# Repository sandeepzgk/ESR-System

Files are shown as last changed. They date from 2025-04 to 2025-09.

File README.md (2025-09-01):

## Electrical Stochastic Resonance (ESR) System : Source Code

This repository hosts the full source for an end‑to‑end ESR system:
- A web‑based RC circuit analyzer (Simulator)
- MicroPython firmware for a Pico W/2W audio device (Firmware)
- A KiCad hardware design for the device (PCB)
- A local experiment runner for ABX/QUEST studies (ABXTester)

Hosted analyzer (no install): https://sandeepzgk.github.io/ESR-System/

### Quick links
- Simulator (web analyzer): Simulator/README.md : hosted at https://sandeepzgk.github.io/ESR-System/
- Firmware (Pico W/2W): Firmware/README.md
- PCB (sr‑device KiCad): PCB/README.md
- ABXTester (experiment runner): ABXTester/readme.md

### Repository structure
- Simulator/ : React + TypeScript single‑page app for ESR RC analysis (sine and noise modes), Tailwind UI, GitHub Pages deploy
- Firmware/ : MicroPython code for Wi‑Fi control and I2S audio playback (HTTP endpoints: play/gain/led/status), Q15 volume scaling
- PCB/ : KiCad project (schematic/PCB), repo‑local libraries and production outputs (v1, v2); JLC importer utility
- ABXTester/ : Flask‑based local runner for experiments (QUEST thresholding + ABX trials), CSV/JSON results

### Citations

#### APA
Kollannur, S., Zhao, F., Chen, Y., & Culbertson, H. (2025). Electrical Stochastic Resonance (ESR) System [Computer software]. GitHub. https://github.com/sandeepzgk/ESR-System

#### MLA
Kollannur, S., Zhao, F., Chen, Y., and Culbertson, H. Electrical Stochastic Resonance (ESR) System. 2025. GitHub, https://github.com/sandeepzgk/ESR-System.

#### Chicago
Kollannur, S., F. Zhao, Y. Chen, and H. Culbertson. 2025. Electrical Stochastic Resonance (ESR) System. GitHub repository. https://github.com/sandeepzgk/ESR-System.

#### BibTeX
```bibtex
@software{esr_system_2025,
  author    = {Kollannur, S. and Zhao, F. and Chen, Y. and Culbertson, H.},
  title     = {Electrical Stochastic Resonance (ESR) System},
  year      = {2025},
  publisher = {GitHub},
  url       = {https://github.com/sandeepzgk/ESR-System},
  note      = {A system for electrical stochastic resonance research including circuit analysis, firmware, hardware design, and experiment tools}
}
```

#### Software Citation Format
Kollannur, S., Zhao, F., Chen, Y., & Culbertson, H. (2025). Electrical Stochastic Resonance (ESR) System [Source code]. GitHub. https://github.com/sandeepzgk/ESR-System : A system for electrical stochastic resonance research including circuit analysis, firmware, hardware design, and experiment tools.

### Brief technical summary
- Web analyzer: React 18 + TypeScript, Tailwind; static SPA deployable to GitHub Pages
- Firmware: MicroPython on RP2040 (Pico W/2W), machine.I2S TX, HTTP API over Wi‑Fi
- Hardware: KiCad project with pinned repo‑local symbol/footprint/3D libraries; production files for fabrication
- Experiments: Python (Flask) with two‑channel audio playback, CSV/JSON logging, QUEST thresholding

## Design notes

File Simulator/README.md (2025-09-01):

## Simulator : ESR RC Circuit Analysis (React + TypeScript)

### 1) Overview
A Create‑React‑App project to explore an AC parallel RC circuit under sine and white‑noise excitation, with safety guidance and units. Features:
- Interactive parameter controls with unit conversion (V, Ω, F, Hz)
- Modes: sine wave and white noise (band‑limited)
- Current distribution and frequency response visualizations
- Noise regime classification via effective ωRC across a band

Key files
- src/RCCircuitAnalysis.tsx : main UI composition
- src/circuitCalculations.ts : unified math for sine and noise modes (ω, effective ωRC, regime)
- src/hooks/useRCCircuit.ts : state, validation, defaults
- src/components/* : charts, controls, results, errors, theory modal
- public/index.html : CRA shell; title set to "ESR Simulator"

### Hosted version
- Use the web app without local setup: https://sandeepzgk.github.io/ESR-System/
- The site is built from this Simulator folder via GitHub Pages (see package.json scripts)

### 2) How to run / deploy
Local dev
- Node 18 recommended
- npm install
- npm start (serves at http://localhost:3000)

Build
- npm run build (outputs to build/)

GitHub Pages
- package.json includes homepage, predeploy, deploy using gh-pages
- npm run deploy publishes build/ to GitHub Pages

Tailwind CSS
- Configured via tailwind.config.js and postcss.config.js; styles in src/index.css

### 3) Where it has been tested
- Local development on Node 18 (per workflow/notes)
- Desktop and mobile layouts; responsive tweaks for small screens

### 4) History and rationale (commit highlights)
- fbdffec (Simulator): Initial CRA app with modular RC analysis and Tailwind styling
- 0ad58a2 (Tailwind): Local Tailwind setup; build pipeline integrated
- 8b760ef/139e43c: 16:9 layout and dashboard‑friendly grid with bug fixes
- b4ca46e: Units system introduced; validation against physical limits
- 65beb42: Added white‑noise mode and UI for band limits
- b949c22 → 863e207 → 1286340: Noise math refined; centralized in circuitCalculations.ts; dimensional correctness
- d57948b/f4cb959: GitHub Pages workflow hardened; caching removed to fix builds
- a7b0789: Homepage switched to ESR‑System for correct Pages base URL

Design choices
- Single math module to avoid duplicated logic between modes
- Declarative UI with validation and explicit unit factors
- CRA + Tailwind for fast iteration; gh‑pages for simple hosting

### 5) Brief technical summary
- Stack: React 18, TypeScript 4.9, CRA 5, Tailwind 3, gh-pages
- Testing: react-scripts test + Testing Library stubs present
- Build targets modern browsers (per browserslist)
- No server required for runtime; static SPA deployable to Pages or any static host

The tissue is modeled as a parallel RC circuit (simplified electrical model)

References used in documentation and model validation:
- Alexander & Sadiku "Fundamentals of Electric Circuits" Chapter 9: Sinusoidal steady-state analysis
- Hayt & Kemmerly "Engineering Circuit Analysis" Chapter 10: AC circuit theory
- IEC 60479 series: Electrical Safety Thresholds and frequency dependence
- IEC 60601-1:2012: Medical device leakage current limits
- MIT OpenCourseWare 8.02T: AC circuit coverage with experimental validation
- Electronics Tutorials: Impedance and phasor analysis with worked examples

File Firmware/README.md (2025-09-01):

## Firmware : Pico 2W Audio Playback and Control

### 1) Overview
Firmware for a Raspberry Pi Pico W/2W running MicroPython to:
- Serve a simple HTTP API over Wi‑Fi for play/gain/LED/status
- Stream stereo PCM audio over I2S to a DAC and class‑D amplifier
- Read raw PCM from on‑device storage with triple‑buffering

Key modules
- main.py : boots Wi‑Fi and hardware, polls for requests, and drives playback
- network_controller.py : Wi‑Fi connect with exponential backoff; simple HTTP server; thread‑safe request passing
- hardware_controller.py : I2S init, DAC/amp control, LED control; in‑place Q15 volume scaling via a @micropython.viper function
- wav_file_player.py : RawFilePlayer: triple‑buffered raw PCM reader with wrap‑around
- config.json : pins, audio parameters (sample_rate, bits, buffer sizes), Wi‑Fi creds
- boot.py : ensures the amplifier shutdown pin is safe on boot
- misc/ : api-tester.py (exercise endpoints), wave-converter.py (WAV→RAW tool)

HTTP endpoints
- GET /play?duration=SECONDS&volume=0.0..1.0 : queue a fixed‑duration playback
- GET /gain?level=0..3 : set amplifier gain pins
- GET /led?num=0..4&state=on|off : control LEDs (0 = all)
- GET /status : return Wi‑Fi/server state and IP

Audio path
- I2S configured from config["audio"] (rate, bits, DMA/buffer sizes)
- Raw PCM file read in fixed‑size frames, scaled in‑place to Q15, written to I2S

### 2) How to deploy / run on hardware
Prerequisites
- Raspberry Pi Pico W/2W flashed with MicroPython
- A RAW PCM file on the device (default filename: my_sound.raw)
- Correct wiring for I2S BCK/LRCK/DATA to the DAC and amp control pins per config.json

Steps
1) Configure
- Edit Firmware/config.json: set network.ssid/password; verify pins and audio settings
- Optionally change audio.playback_frames/dma_buffer_frames for your I2S driver
2) Copy files to the board
- Copy all Firmware/*.py and config.json to the device (e.g., Thonny, mpremote)
- Copy your RAW audio file as my_sound.raw (or update main.py accordingly)
3) Boot and run
- Reset the board; boot.py sets amp shutdown low; main() starts automatically if invoked
- The Wi‑Fi controller runs on the second core/thread and starts the HTTP server
4) Invoke playback (examples)
- curl "http://<PICO_IP>/play?duration=5&volume=0.5"
- curl "http://<PICO_IP>/gain?level=2"
- curl "http://<PICO_IP>/led?num=0&state=on"; curl "http://<PICO_IP>/status"

Converting WAV to RAW
- Use Firmware/misc/wave-converter.py to resample/convert WAV → interleaved RAW matching config["audio"]

### 3) Where it has been tested
- On Raspberry Pi Pico 2W hardware with MicroPython (RP2040 + Wi‑Fi)
- Exercised via misc/api-tester.py and curl from a local network
- Exact MicroPython version and DAC/amp models depend on your setup; pins are configurable

### 4) History and rationale (commit highlights)
- 3d118a1 (Firmware): Initial firmware: I2S + Wi‑Fi + raw file player; simple HTTP API to decouple host and device
- c961120 (misc tools): Added wave-converter.py and moved api-tester under misc for easier audio prep and endpoint testing

Design choices
- Fixed‑point Q15 scaling in a @micropython.viper routine for fast per‑buffer volume without floating point
- Exponential backoff Wi‑Fi connect with LED signaling for robustness
- Triple‑buffer file reader to minimize glitches while looping
- Config‑driven pins/buffers so firmware can be tuned without code changes

### 5) Brief technical summary
- Platform: MicroPython on RP2040 (Pico W/2W) with _thread concurrency
- Peripherals: machine.I2S TX; GPIOs for DAC mute, amp gain (2 bits), amp shutdown, LEDs
- Networking: network + sockets, simple GET API, cooperative loop with short timeouts
- Audio: raw interleaved PCM, DMA‑sized I2S buffer, optional playback_frames override
- Synchronization: lock‑protected request queue (play/gain), state flags to reject concurrent play

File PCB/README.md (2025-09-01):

## PCB SR Device KiCad Project

### 1) Overview
KiCad project for the ESR hardware: a Pico‑based audio playback/amp board ("sr-device"). Includes:
- KiCad schematic, PCB, and project files (sr-device.kicad_*)
- Curated symbol/footprint/3D libraries under PCB/lib for key parts (DAC, amplifier, regulators, passives, connectors)
- Production outputs under PCB/production/v1 and v2 (BOM, positions, designators, zipped fab packages)
- jlcimporter.py utility to generate and normalize part libraries using JLC2KiCadLib

Notable parts
- DAC: PCM5100A
- Amplifier: TPA3112D1
- Regulators: LM78M05C, LM7812S, LM1085IS-12, AP7333-33
- Inductors/caps/resistors; Pico headers/footprints; custom logos

### 2) How to open / produce outputs
Open in KiCad 7/8
- Open PCB/sr-device.kicad_pro; KiCad will resolve sym-lib-table and fp-lib-table to PCB/lib/*

Generate fabrication
- Use KiCad’s Plot and Fabrication Toolkit (options in fabrication-toolkit-options.json)
- Export Gerbers, drill files, position files, and BOM as needed

JLC integration workflow
- jlcimporter.py wraps JLC2KiCadLib to create per‑part libraries under PCB/lib/<MFR_PART>/
- It normalizes filenames (symbol.kicad_sym, footprint.kicad_mod, model.step) and updates lib tables
- Run from PCB/: python jlcimporter.py --lcsc_part_numbers C12345 C67890

### 3) Where it has been tested
- Designed and opened in KiCad; produced v1 and v2 outputs in PCB/production
- Libraries resolved via sym-lib-table and fp-lib-table within this project (KIPRJMOD relative paths)

### 4) History and rationale (commit highlights)
- 79621ca (PCB): Initial KiCad project checked in with curated libraries and production artifacts (v1, v2)
- Custom library structure chosen for reproducibility and to avoid external dependency drift; jlcimporter.py automates bringing JLC parts into repo‑local libs

Design choices
- Repo‑local symbol/footprint/3D models for repeatable builds and offline use
- KIPRJMOD‑relative paths in lib tables so the project remains portable
- Versioned production output directories to track released fab packages

### 5) Brief technical summary
- EDA: KiCad project with sym/fp tables pinned to PCB/lib
- Manufacturing: BOM/pos/designator exports for JLC; STEP models included for 3D
- Utilities: Python importer normalizes JLC outputs and patches lib tables

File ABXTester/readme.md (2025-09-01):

## ABXTester : Experiment Runner

### 1) Overview
ABXTester is a local Flask web app for running audio psychophysics experiments that combine:
- QUEST threshold estimation to calibrate the stochastic-resonance (SR) noise level
- ABX trials over a texture dataset
- Durable CSV/JSON logging

Core modules
- managers/flaskapp.py : Minimal page queue and event routing to Jinja2 templates
- managers/stereoaudioplayer.py : Two‑channel playback (soundfile + simpleaudio) with independent gains
- managers/questestimation.py : QUEST wrapper (max trials, start value)
- managers/experimentreader.py : CSV‑driven condition sequencing
- managers/atomicwriter.py : Atomic appends for results files

Data layout (relative to ABXTester/)

``` Note: This data is not included because of IP. Please contact the author for more information. ```
- dataset/v2024dataset.csv : Trial/experiment conditions
- media/textures/ : Left‑channel textures (WAV)
- dataset/stochastic_noise.wav : Right‑channel SR noise (WAV)
- results/ : Output CSV and QUEST JSON snapshots

Entry point: main.py orchestrates page flow (instructions → QUEST → trial → experiment → survey) and wires event handlers.

### 2) How to deploy/run
Prerequisites
- Conda/Miniconda
- Working audio output device
- Windows is the primary target (env includes pywin32/pypiwin32); Linux/macOS may work with minor tweaks

Steps
1. Environment
   - conda env create -f environment.yml
   - conda activate abx_tester
2. Assets
   - Ensure dataset/v2024dataset.csv, dataset/stochastic_noise.wav, and media/textures/* exist
   - Create results/ directory if missing
3. Launch
   - python main.py <PARTICIPANT_ID>
   - Open http://127.0.0.1:5000
4. Operation
   - Use the web UI; app posts to /event and advances pages via a queue
   - Outputs: results/<PARTICIPANT_ID>_experiment_results.csv and <PARTICIPANT_ID>_quest_results.csv (+ .json)

Notes
- Sample rates must match between the two input WAVs; the player enforces this
- Right channel SR amplitude is QUEST_MEAN × SRPresentationLVL (per trial row)

### 3) Where it has been tested
- Windows 10/11 with Anaconda/Miniconda
- Python 3.11 as pinned in environment.yml
- Chromium‑based browsers locally
- simpleaudio backend (WASAPI/DirectSound on Windows)

### 4) History and rationale (commit highlights)
- d90c32e (ABXTester): Initial Flask app with audio playback, CSV I/O, QUEST, and templates : goal: unify thresholding and ABX in a lightweight local runner with durable logging
- Environment pinned in environment.yml for reproducible audio/science stacks (NumPy/SciPy/Librosa/simpleaudio/PsychoPy)

Design choices
- Minimal Flask wrapper (page queue + event routing) for easy experiment customization
- Atomic writes to prevent truncated CSVs in the presence of interruptions
- Explicit media/dataset layout to separate stimuli from code

### 5) Brief technical summary
- Language: Python 3.11
- Frameworks/Libraries: Flask + Jinja2, NumPy, soundfile (libsndfile), simpleaudio, pandas, pytz
- Architecture: Single‑process Flask; event‑driven page transitions; synchronous audio playback guarded by a simple AudioManager
- I/O: CSV conditions → in‑memory row; responses → atomic CSV + QUEST JSON snapshots

# Conda Environment Setup for ABX Tester Project

This guide will help you set up a Conda environment for the ABX Tester project using the `environment.yml` file.

## Prerequisites

- [Anaconda](https://www.anaconda.com/products/individual) or [Miniconda](https://docs.conda.io/en/latest/miniconda.html) installed on your system.

## Setup Steps

### 1. Clone the Project Repository (if applicable)

If your project is in a Git repository, clone it using the command below. Otherwise, navigate to your project directory.

```bash
git clone <repository-url>
cd <project-directory>
```

### 2. Create the Conda Environment

Create the Conda environment from the provided `environment.yml` file:

```bash
conda env create -f environment.yml
```

This will:
- Create a new Conda environment named `abx_tester`.
- Install all the necessary dependencies listed in the `environment.yml` file using Conda and pip.

### 3. Activate the Environment

After the environment is created, activate it with the following command:

```bash
conda activate abx_tester
```

### 4. Verify the Installation

To verify that everything is installed correctly, you can run a simple Python script that imports all the required libraries:

```python
import numpy
import pandas
import scipy
import matplotlib
import seaborn
import librosa
import soundfile
import sklearn
import pytz
import flask
import psychopy
import simpleaudio

print("All libraries imported successfully!")
```

Save this script as `test_imports.py` and run it:

```bash
python test_imports.py
```

If you see the success message without any errors, your environment is set up correctly.

### 5. Updating the Environment

If new dependencies are added to the project in the future, you can update the environment by running:

```bash
conda env update --file environment.yml --prune
```

This will install any new dependencies and remove packages no longer required.

### 6. Removing the Environment

If you ever need to remove the Conda environment, you can do so with:

```bash
conda remove --name abx_tester --all
```

## Troubleshooting

- **If you encounter issues with PyAudio**, you might need to install `portaudio`:
  ```bash
  conda install -c anaconda portaudio
  ```

- **For issues with PsychoPy**, you can try reinstalling it:
  ```bash
  conda install -c conda-forge psychopy
  ```

- **On Windows**, if you encounter issues with `librosa`, try installing `numpy` with MKL:
  ```bash
  conda install -c conda-forge numpy=1.21
  ```

## Environment Overview

### `environment.yml` Contents:
```yaml
name: abx_tester
channels:
  - defaults
  - conda-forge
dependencies:
  - python=3.8
  - numpy
  - pandas
  - matplotlib
  - seaborn
  - scipy
  - soundfile
  - psychopy
  - librosa
  - flask
  - scikit-learn
  - pip
  - pip:
      - simpleaudio
      - pytz
```

This file lists the Conda and pip packages needed to run the project. Conda will install the core libraries, while pip will handle the few additional Python-only packages.

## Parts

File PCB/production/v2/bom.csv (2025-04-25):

Designator | Footprint | Quantity | Value | LCSC Part #
C1, C4 | 0603 | 2 | 2.2uF | C57895
C10, C12, C22, C7 | 0603 | 4 | 10uF | C386081
C11, C14, C15, C16, C17, C19, C24, C27, C5, C8, C9 | 0603 | 11 | 100nF | C88219
C13, C20, C21, C29, C30, C31, C32, C33, C6 | 0603 | 9 | 1uF | C841050
C18 | 0603 | 1 | 0.22uF | C107083
C2, C3 | 0603 | 2 | 2.2nF | C2835509
C23, C26, C34, C36, C40, C41 | 0603 | 6 | 1nF | C340644
C25, C28 | CP_Elec_6.3x5.4 | 2 | 100uF | C2887272
C35, C37 | 0603 | 2 | 0.68uF | C694504
C38, C39 | 0603 | 2 | 0.47uF | C162281
C43 | TAJC686K016RNJ | 1 | 68uF | C7220
D1, D2, D3, D4, D5 | 0603 | 5 | LED_Small | C89811
FB1, FB3 | 0805 | 2 | 80Ω | C2971887
FB2, FB4 | 1806 | 2 | 75Ω | C14586
J1, J2 | KF301-5_0-2P | 2 | KF301-5_0-2P | C474881
J3 | PinHeader_1x02_P2.54mm_Vertical | 1 | Conn_01x02_Pin | DNP
L1, L2 | IHLP3232DZER220M11 | 2 | 22uH | C845053
R1, R2, R3 | 0603 | 3 | 56R | C227967
R11, R12, R13, R14, R21 | 0603 | 5 | 1K | C73797
R15, R16, R17, R18, R19, R20, R4, R7 | 0603 | 8 | 10K | C465463
R22, R23, R24 | 0603 | 3 | 10R | C441910
R5, R6 | 0603 | 2 | 470R | C114669
RV1 | VG039NSNXTB103 | 1 | 10K, originally C515300, now using, C719176 | C719176
SW1 | PTS636SK25SMTRLFS | 1 | PTS636SK25SMTRLFS | C2689642
SW2 | SS-12D11L7 | 1 | SS-12D11L7 | C2884775
U1 | RPi_Pico_SMD_TH | 1 | Pico | DNP
U2 | TO-263-3_TabPin4 | 1 | LM7812S/TR, was LM1085IS-12/NOPB, originally C130908, now C507140, changed for cost | C507140
U11 | TPA3112D1PWPR | 1 | TPA3112D1PWPR | C133544
U3 | Package_SO:TSSOP-20_4.4x6.5mm_P0.65mm | 1 | PCM5100APWR | C131154
U8 | LM78M05CDTX-NOPB | 1 | LM78M05CDTX/NOPB, originally C544492, now using, C5145267 | C5145267
U9 | AP7333-33SRG-7 | 1 | AP7333-33SRG-7 | C150745

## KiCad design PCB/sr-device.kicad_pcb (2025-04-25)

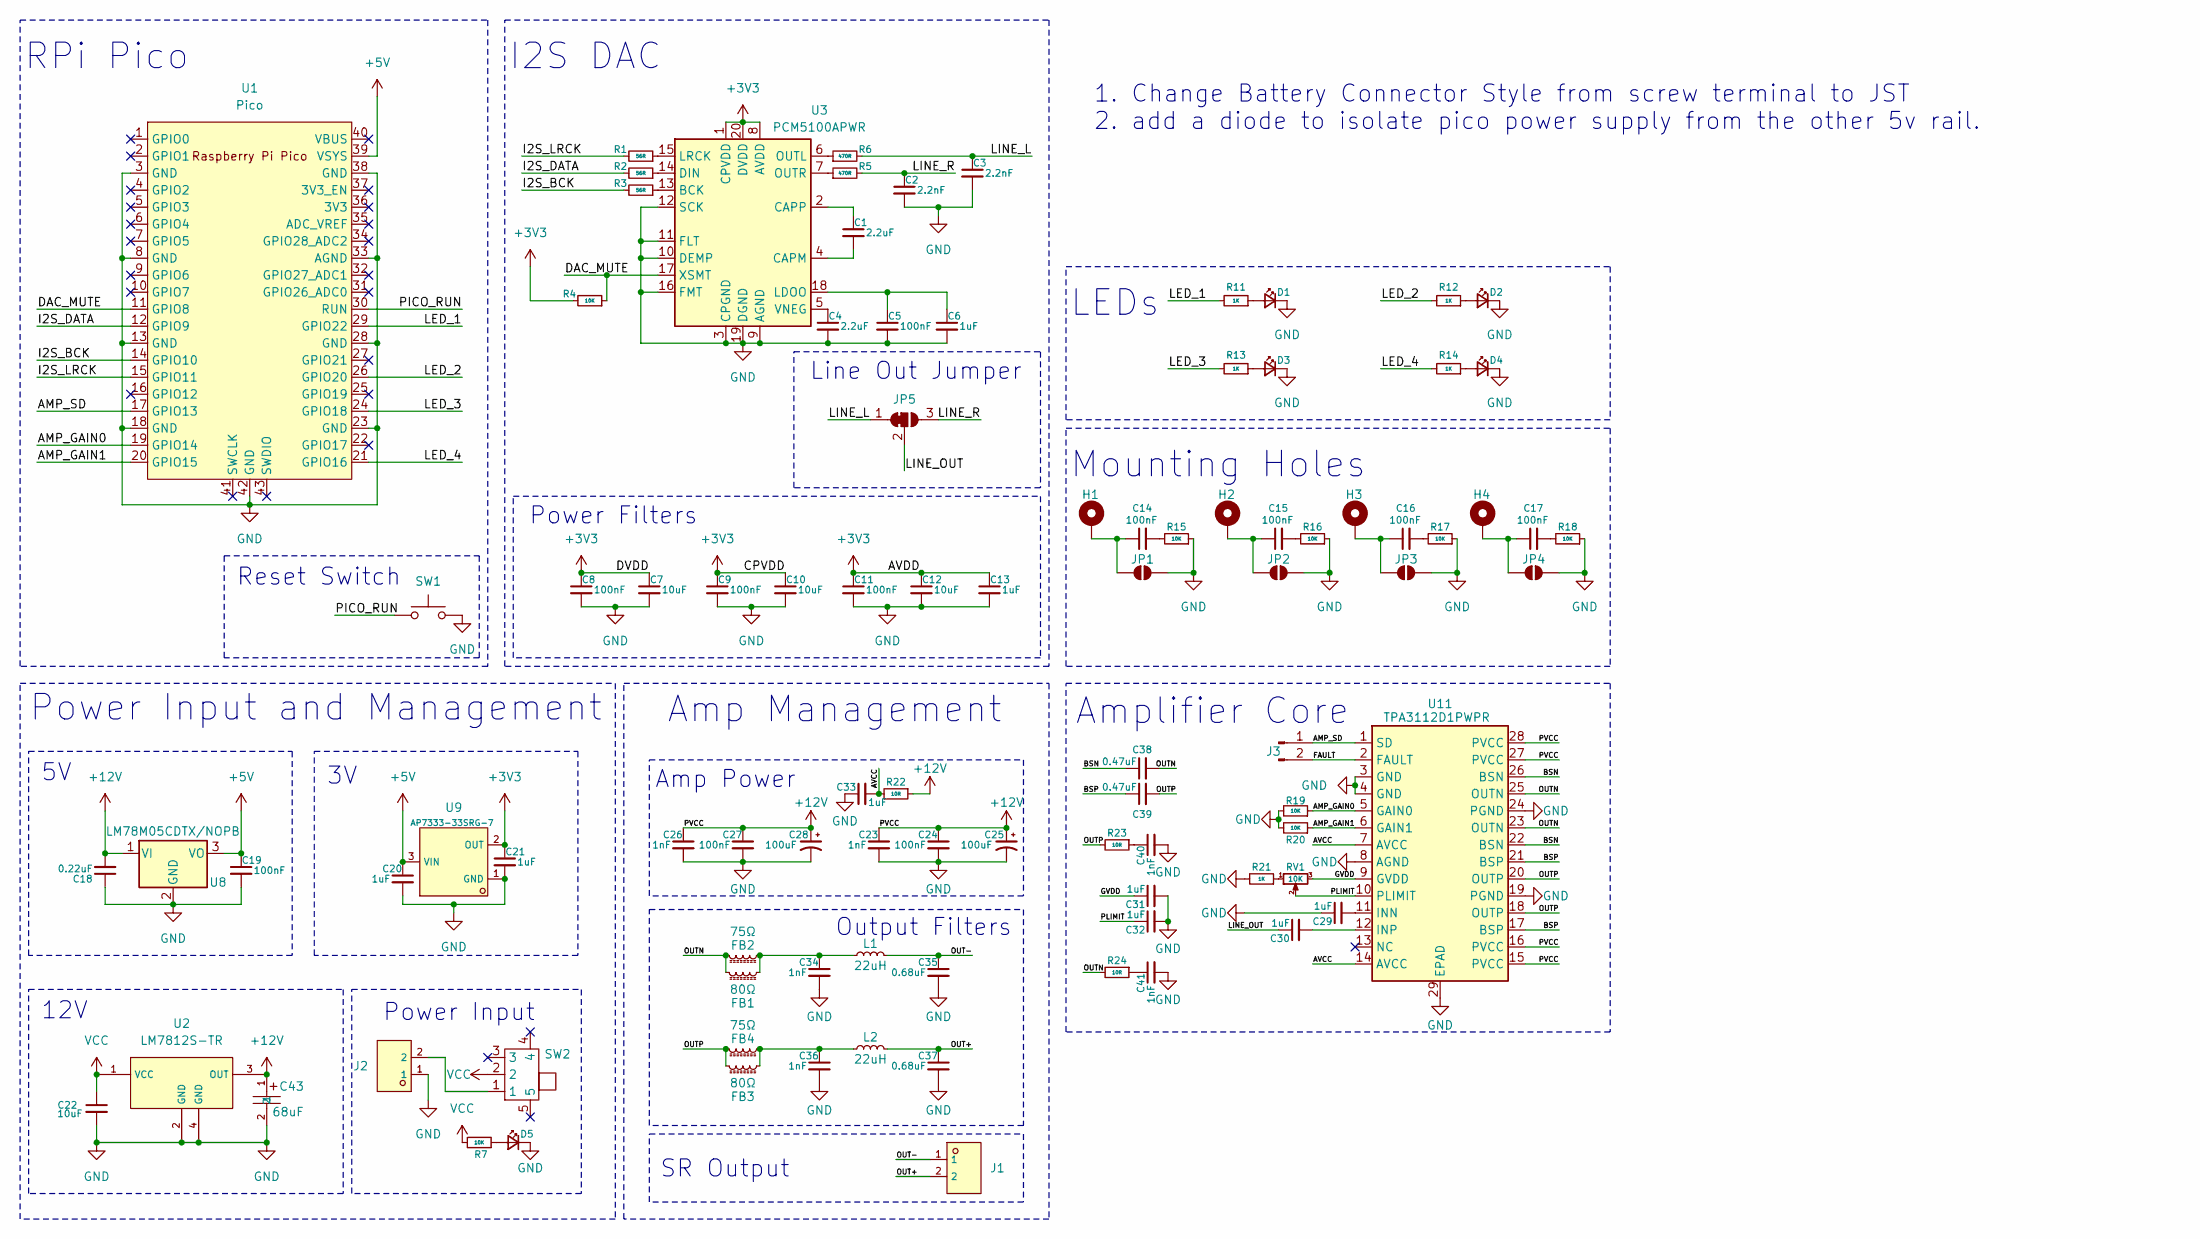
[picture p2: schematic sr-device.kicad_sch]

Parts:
C1, C4: 2.2uF; C_0603_1608Metric; LCSC C57895
C2, C3: 2.2nF; C_0603_1608Metric; LCSC C2835509
C5, C8, C9, C11, C14, C15, C16, C17, C19, C24, C27: 100nF; C_0603_1608Metric; LCSC C88219
C6, C13, C20, C21, C29, C30, C31, C32, C33: 1uF; C_0603_1608Metric; LCSC C841050
C7, C10, C12, C22: 10uF; C_0603_1608Metric; LCSC C386081
C18: 0.22uF; C_0603_1608Metric; LCSC C107083
C23, C26, C34, C36, C40, C41: 1nF; C_0603_1608Metric; LCSC C340644
C25, C28: 100uF; CP_Elec_6.3x5.4; LCSC C2887272
C35, C37: 0.68uF; C_0603_1608Metric; LCSC C694504
C38, C39: 0.47uF; C_0603_1608Metric; LCSC C162281
C43: 68uF; footprint; LCSC C7220
D1, D2, D3, D4, D5: LED_Small; LED_0603_1608Metric; LCSC C89811
FB1, FB3: 80Ω; L_0805_2012Metric; LCSC C2971887
FB2, FB4: 75Ω; L_1806_4516Metric; LCSC C14586
H1, H2, H3, H4: MountingHole; MountingHole_3.2mm_M3_ISO7380_Pad
J1, J2: KF301-5_0-2P; footprint; LCSC C474881
J3: Conn_01x02_Pin; PinHeader_1x02_P2.54mm_Vertical; LCSC DNP
JP1, JP2, JP3, JP4: SolderJumper_2_Open; SolderJumper-2_P1.3mm_Open_TrianglePad1.0x1.5mm
JP5: SolderJumper_3_Bridged12; SolderJumper-3_P1.3mm_Bridged12_RoundedPad1.0x1.5mm
L1, L2: 22uH; footprint; LCSC C845053
R1, R2, R3: 56R; R_0603_1608Metric; LCSC C227967
R4, R7, R15, R16, R17, R18, R19, R20: 10K; R_0603_1608Metric; LCSC C465463
R5, R6: 470R; R_0603_1608Metric; LCSC C114669
R11, R12, R13, R14, R21: 1K; R_0603_1608Metric; LCSC C73797
R22, R23, R24: 10R; R_0603_1608Metric; LCSC C441910
RV1: 10K; footprint; LCSC C515300
SW1: PTS636SK25SMTRLFS; footprint; LCSC C2689642
SW2: SS-12D11L7; LCSC C2884775
U1: Pico; RPi_Pico_SMD_TH
U2: LM7812S-TR; footprint; LCSC C507140
U3: PCM5100APWR; TSSOP-20_4.4x6.5mm_P0.65mm; LCSC C131154
U8: LM78M05CDTX/NOPB; footprint; LCSC C544492
U9: AP7333-33SRG-7; footprint; LCSC C150745
U11: TPA3112D1PWPR; footprint; LCSC C133544

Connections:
+3V3: C7.1, C8.1, C9.1, C10.1, C11.1, C12.1, C13.1, C21.1, R4.2, U3.1 (CPVDD), U3.8 (AVDD), U3.20 (DVDD), U9.2 (OUT)
+5V: C19.1, C20.1, U1.39 (VSYS), U8.3 (VO), U9.3 (VIN)
+12V: C18.2, C23.1, C24.1, C25.1, C26.1, C27.1, C28.1, C43.1, R22.1, U2.3 (OUT), U8.1 (VI), U11.15 (PVCC), U11.16 (PVCC), U11.27 (PVCC), U11.28 (PVCC)
/AMP_GAIN0: R19.1, U1.19 (GPIO14), U11.5 (GAIN0)
/AMP_GAIN1: R20.1, U1.20 (GPIO15), U11.6 (GAIN1)
/AMP_SD: J3.1, U1.17 (GPIO13), U11.1 (SD)
/AVCC: C33.2, R22.2, U11.7 (AVCC), U11.14 (AVCC)
/BSN: C38.1, U11.22 (BSN), U11.26 (BSN)
/BSP: C39.1, U11.17 (BSP), U11.21 (BSP)
/DAC_MUTE: R4.1, U1.11 (GPIO8), U3.17 (XSMT)
/FAULT: J3.2, U11.2 (FAULT)
/GVDD: C31.1, RV1.3, U11.9 (GVDD)
/I2S_BCK: R3.2, U1.14 (GPIO10)
/I2S_DATA: R2.2, U1.12 (GPIO9)
/I2S_LRCK: R1.2, U1.15 (GPIO11)
/LED_1: R11.2, U1.29 (GPIO22)
/LED_2: R12.2, U1.26 (GPIO20)
/LED_3: R13.2, U1.24 (GPIO18)
/LED_4: R14.2, U1.21 (GPIO16)
/LINE_L: C3.1, JP5.1 (A), R6.2
/LINE_OUT: C30.1, JP5.2 (C)
/LINE_R: C2.1, JP5.3 (B), R5.2
/OUT+: C37.1, J1.2, L2.1
/OUT-: C35.1, J1.1, L1.1
/OUTN: C38.2, FB1.2, FB2.2, R24.2, U11.23 (OUTN), U11.25 (OUTN)
/OUTP: C39.2, FB3.2, FB4.2, R23.2, U11.18 (OUTP), U11.20 (OUTP)
/PICO_RUN: SW1.1, U1.30 (RUN)
/PLIMIT: C32.1, RV1.2, U11.10 (PLIMIT)
GND: C2.2, C3.2, C4.2, C5.2, C6.2, C7.2, C8.2, C9.2, C10.2, C11.2, C12.2, C13.2, C18.1, C19.2, C20.2, C21.2, C22.2, C23.2, C24.2, C25.2, C26.2, C27.2, C28.2, C29.1, C31.2, C32.2, C33.1, C34.2, C35.2, C36.2, C37.2, C40.2, C41.2, C43.2, D1.1 (K), D2.1 (K), D3.1 (K), D4.1 (K), D5.1 (K), J2.1, JP1.2 (B), JP2.2 (B), JP3.2 (B), JP4.2 (B), R15.1, R16.1, R17.1, R18.1, R19.2, R20.2, R21.2, SW1.2, U1.3 (GND), U1.8 (GND), U1.13 (GND), U1.18 (GND), U1.23 (GND), U1.28 (GND), U1.33 (AGND), U1.38 (GND), U1.42 (GND), U2.2 (GND), U2.4 (GND), U3.3 (CPGND), U3.9 (AGND), U3.10 (DEMP), U3.11 (FLT), U3.12 (SCK), U3.16 (FMT), U3.19 (DGND), U8.2 (GND), U9.1 (GND), U11.3 (GND), U11.4 (GND), U11.8 (AGND), U11.19 (PGND), U11.24 (PGND), U11.29 (EPAD)
unnamed: C14.2, R15.2
unnamed: C15.2, R16.2
unnamed: C16.2, R17.2
unnamed: C17.2, R18.2
unnamed: C34.1, FB1.1, FB2.1, L1.2
unnamed: C36.1, FB3.1, FB4.1, L2.2
unnamed: C40.1, R23.1
unnamed: C41.1, R24.1
unnamed: D1.2 (A), R11.1
unnamed: D2.2 (A), R12.1
unnamed: D3.2 (A), R13.1
unnamed: D4.2 (A), R14.1
unnamed: D5.2 (A), R7.1
unnamed: J2.2, SW2.1
unnamed: C14.1, H1.1, JP1.1 (A)
unnamed: C15.1, H2.1, JP2.1 (A)
unnamed: C16.1, H3.1, JP3.1 (A)
unnamed: C17.1, H4.1, JP4.1 (A)
unnamed: R21.1, RV1.1
unnamed: R3.1, U3.13 (BCK)
unnamed: C1.2, U3.4 (CAPM)
unnamed: C1.1, U3.2 (CAPP)
unnamed: R2.1, U3.14 (DIN)
unnamed: C5.1, C6.1, U3.18 (LDOO)
unnamed: R1.1, U3.15 (LRCK)
unnamed: R6.1, U3.6 (OUTL)
unnamed: R5.1, U3.7 (OUTR)
unnamed: C4.1, U3.5 (VNEG)
unnamed: C29.2, U11.11 (INN)
unnamed: C30.2, U11.12 (INP)
VCC: C22.1, R7.2, SW2.2, U2.1 (VCC)

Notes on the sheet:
Mounting Holes
RPi Pico
Power Filters
1. Change Battery Connector Style from screw terminal to JST 2. add a diode to isolate pico power supply from the other 5v rail.
Power Input and Management
LEDs
Amp Management
SR Output
Output Filters
I2S DAC
Line Out Jumper
Reset Switch
Amplifier Core
12V
Amp Power
Power Input

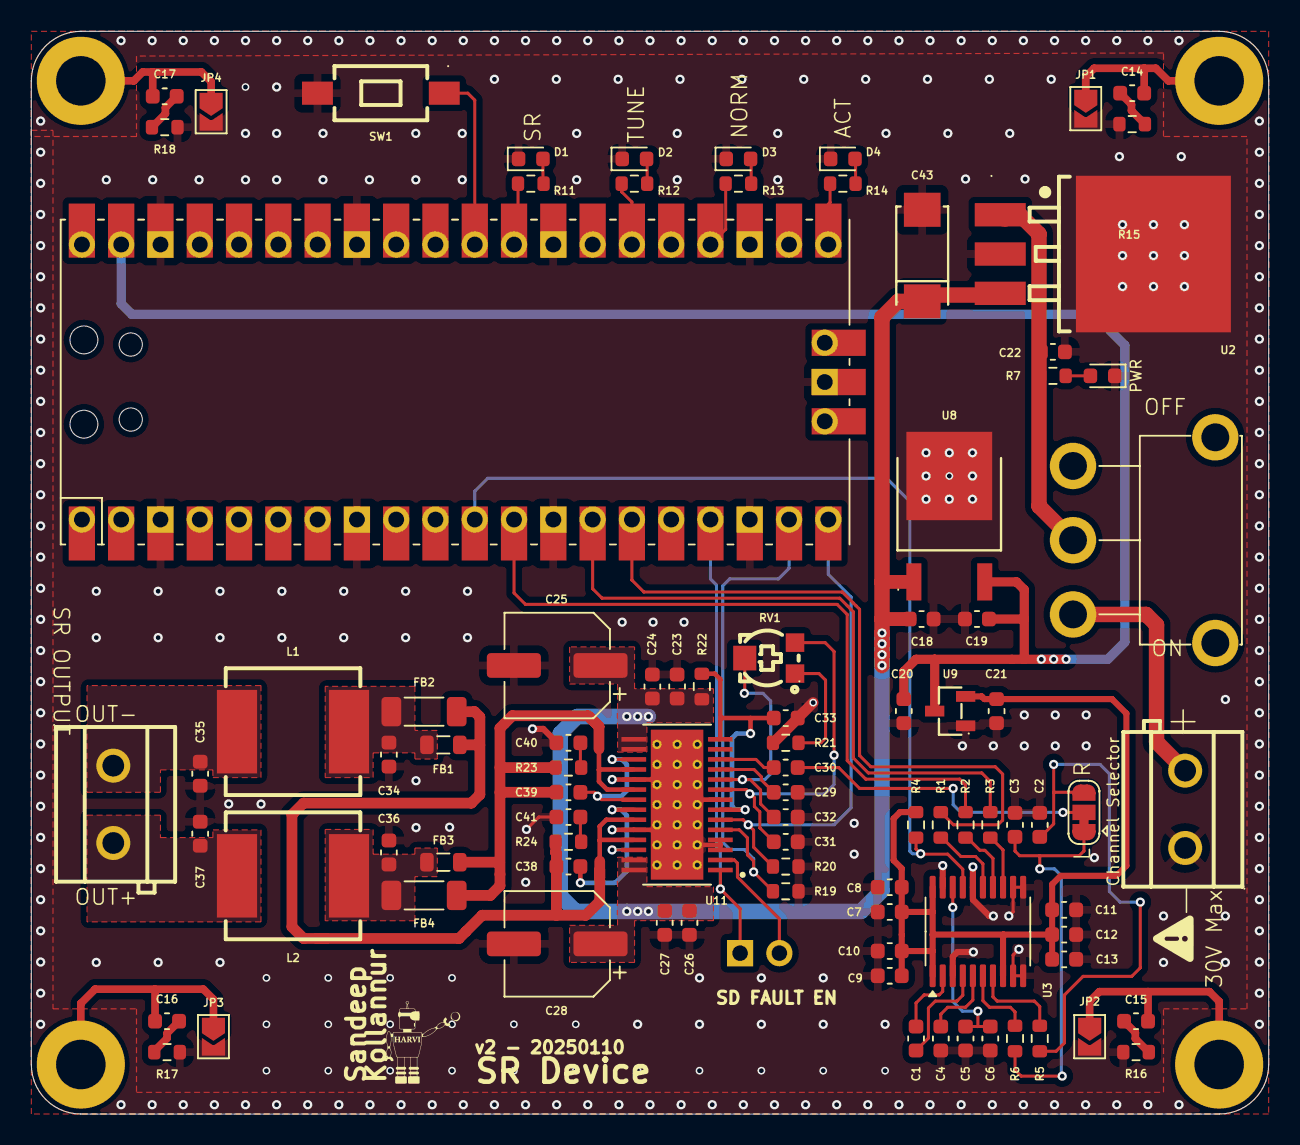
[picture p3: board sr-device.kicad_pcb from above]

Board: 2 copper layers, 80.0 x 70.0 mm, 95 parts (1 on the bottom side), 60 nets.

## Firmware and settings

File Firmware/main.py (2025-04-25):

import time
import json
from hardware_controller import HardwareController
from wav_file_player import RawFilePlayer
import _thread 
from network_controller import WiFiController

def load_config():
    """Load configuration from config.json file."""
    try:
        with open('config.json', 'r') as f:
            return json.load(f)
    except Exception as e:
        print("Error loading config.json. Using default settings.", e)
        return {}

def main():
    # Load configuration settings
    config = load_config()

    # Initialize WiFi controller and start it on the second core
    wifi = WiFiController(config)
    wifi.start()

    # Initialize the hardware controller and blink the LED
    hw = HardwareController(config)
    hw.blink_led(5) # Blink LED 5 times to indicate startup
    time.sleep(0.5)

    # Initialize I2S hardware
    hw.initialize_i2s()

    # Create the raw PCM file player
    file_player = RawFilePlayer("my_sound.raw", config)

    #

    # Determine playback frames from config (fallback to buffer_length)
    adjusted_frames = config.get("audio", {}).get("playback_frames",
                            config.get("audio", {}).get("buffer_length", 1024))
    print(f"\nUsing playback_frames = {adjusted_frames}")

    # Main loop - check for requests from the WiFi controller
    while True:
        # Check for gain change requests
        gain_level = wifi.check_gain_request()
        if gain_level is not None:
            print(f"Setting amplifier gain to level {gain_level}")
            hw.set_gain(gain_level)
            
        # Check for play requests
        play_request = wifi.check_play_request()
        if play_request:
            # We have a play request - start audio playback
            duration = play_request['duration']
            volume = play_request['volume']
            
            print(f"Playing audio: duration={duration}s, volume={volume}")
            
            try:
                hw.play_audio(
                    wave_generator=file_player,
                    playback_frames=adjusted_frames,
                    aggregate_count=1,
                    debug=True,
                    duration_seconds=duration,
                    volume=volume
                )
            finally:
                # Mark playback as complete
                with wifi.play_request_lock:
                    wifi.audio_playing = False
                    
                    # Give other tasks a chance to run
                    time.sleep_ms(100)

if __name__ == "__main__":
    main()

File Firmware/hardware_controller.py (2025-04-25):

from machine import Pin, I2S
import time, gc
import micropython

# --------------------
# fixed‑point scaler: in-place scale of signed 16‑bit samples
# scale a bytearray in-place, sample‑wise, with fixed-point Q15 volume
@micropython.viper
def _viper_scale16(buf: ptr8, n: int, vol_q15: int):
    i = int(0)
    # n = number of 16‑bit samples; buf is ptr8 to bytes
    while i < n:
        off = i * 2
        lo = buf[off]              # low byte
        hi = buf[off + 1]          # high byte
        raw = lo | (hi << 8)       # assemble little‑endian word
        # signed conversion
        if raw & 0x8000:
            s = raw - 0x10000
        else:
            s = raw
        # Q15 scale
        s = (s * vol_q15) >> 15
        # clamp
        if s < -32768:
            s = -32768
        elif s > 32767:
            s = 32767
        # write back
        v = s & 0xFFFF
        buf[off]     = v & 0xFF
        buf[off + 1] = (v >> 8) & 0xFF
        i += 1


# --------------------

class HardwareController:    
    def __init__(self, config):
        self.config = config
        self.audio = config["audio"]
        self.led = Pin(config["pins"]["led"], Pin.OUT)
        self.i2s = None

        self.dac_mute = Pin(config["pins"]["mute"], Pin.OUT)
        self.amp_gain0 = Pin(config["pins"]["amp_gain0"], Pin.OUT)
        self.amp_gain1 = Pin(config["pins"]["amp_gain1"], Pin.OUT)
        self.amp_sd = Pin(config["pins"]["amp_sd"], Pin.OUT)

    def blink_led(self, count):
        for _ in range(count):
            self.led.on()
            time.sleep(0.2)
            self.led.off()
            time.sleep(0.2)

    def enable_audio(self):
        """Enable audio output by unmuting DAC and enabling amplifier."""
        self.dac_mute.value(1)
        self.amp_sd.value(1)
        print("DAC and amplifier enabled")  

    def disable_audio(self):
        """Disable audio output by muting DAC and disabling amplifier."""
        self.dac_mute.value(0)
        self.amp_sd.value(0)
        print("DAC and amplifier disabled")

    def set_gain(self, gain_level):
        """
        Set amplifier gain level.
        gain_level: 0-3 (0: +20dB, 1: +26dB, 2: +32dB, 3: +36dB)
        """
        if gain_level < 0 or gain_level > 3:
            raise ValueError("Gain level must be between 0 and 3")
        self.amp_gain0.value(gain_level & 0x01)
        self.amp_gain1.value((gain_level >> 1) & 0x01)
        print(f"Amplifier gain set to level {gain_level}")        

    def initialize_i2s(self):
        """
        Initialize I2S interface with a DMA buffer sized in bytes.
        Uses 'dma_buffer_frames' (or falls back to 'buffer_length') and
        the pins from self.config["pins"].
        """
        # bytes per stereo frame = (bits per sample / 8) × 2 channels
        frame_size = (self.audio["bits_per_sample"] // 8) * 2

        # pick dma_buffer_frames if present, else buffer_length
        dma_frames = self.audio.get("dma_buffer_frames", self.audio["buffer_length"])
        ibuf_size = dma_frames * frame_size

        print(f"Initializing I2S: Using DMA buffer frames = {dma_frames} (ibuf = {ibuf_size} bytes)")

        pins = self.config["pins"]
        # id=0 must be passed positionally; pins come in as keywords
        self.i2s = I2S(
            0,                           # I2S peripheral ID as positional
            sck=Pin(pins["bck"]),        # BCK (bit clock)
            ws=Pin(pins["lrck"]),        # LRCK / WS (word select)
            sd=Pin(pins["data"]),        # SD (serial data)
            mode=I2S.TX,
            bits=self.audio["bits_per_sample"],
            format=I2S.STEREO,
            rate=self.audio["sample_rate"],
            ibuf=ibuf_size
        )


    def play_audio(self,
                   wave_generator,
                   playback_frames=None,
                   aggregate_count=16,
                   debug=False,
                   duration_seconds=None,
                   volume: float = 1.0):
        """
        volume: float in [0.0, 1.0]
        """
        import gc, time

        # pre‑compute integer Q15 volume
        vol_q15 = int(volume * 32767)

        # 1) determine frames per write
        if playback_frames is None:
            playback_frames = self.audio.get(
                "playback_frames",
                self.audio["buffer_length"]
            )

        # 2) init I2S if needed
        if self.i2s is None:
            self.initialize_i2s()

        # 3) free memory & enable audio
        gc.collect()
        self.enable_audio()

        # 4) fixed‑duration?
        if duration_seconds is not None:
            duration_ms = int(duration_seconds * 1000)
            start_ms = time.ticks_ms()
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

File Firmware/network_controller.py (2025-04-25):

import network
import socket
import time
import json
import _thread
from machine import Pin
import gc

class WiFiController:
    def __init__(self, config):
        self.config = config
        self.network_config = config.get("network", {})
        self.ssid = self.network_config.get("ssid", "")
        self.password = self.network_config.get("password", "")
        self.server_port = self.network_config.get("server_port", 80)
        
        # Reconnection parameters
        self.max_retries = self.network_config.get("max_retries", 10)
        self.initial_retry_delay = self.network_config.get("initial_retry_delay_ms", 500)
        self.max_retry_delay = self.network_config.get("max_retry_delay_ms", 30000)
        self.backoff_factor = self.network_config.get("backoff_factor", 2)

        # State variables
        self.wifi_connected = False
        self.server_running = False
        self.audio_playing = False
        
        # Initialize shared resources and synchronization
        self.play_request_lock = _thread.allocate_lock()
        self.play_request = None
        self.gain_request = None
        
        # LEDs - get pin numbers from config
        pins = config.get("pins", {})
        self.leds = [
            Pin(pins.get("led1", 22), Pin.OUT),  # LED 1
            Pin(pins.get("led2", 20), Pin.OUT),  # LED 2
            Pin(pins.get("led3", 18), Pin.OUT),  # LED 3
            Pin(pins.get("led4", 16), Pin.OUT),  # LED 4
        ]
        
        # Wait briefly before WiFi initialization
        time.sleep(1)

        # Initialize WiFi interface
        self.wlan = network.WLAN(network.STA_IF)
        self.wlan.active(True)
        
        time.sleep(1)  # Wait for the interface to be active
    
    def set_led(self, led_num, state):
        """Control a specific LED by number (1-4)"""
        #print(f"Setting LED {led_num} to {'ON' if state else 'OFF'}")
        if 0 <= led_num <= 4:
            self.leds[led_num-1].value(1 if state else 0)
        else:
            print(f"Invalid LED number: {led_num}")
    
    def set_all_leds(self, state):
        """Set all LEDs to the same state"""
        for led in self.leds:
            led.value(1 if state else 0)
    
    def blink_all_leds(self, count, interval_ms=500):
        """Blink all LEDs a specified number of times"""
        for _ in range(count):
            self.set_all_leds(True)
            time.sleep_ms(interval_ms)
            self.set_all_leds(False)
            time.sleep_ms(interval_ms)

    def connect_wifi(self):
        """Connect to WiFi with exponential backoff and improved error handling"""
        try:
            if not self.ssid or not self.password:
                print("WiFi credentials not configured")
                return False
            
            print(f"Connecting to WiFi: {self.ssid}")
            print(f"Memory before connect: {gc.mem_free()} bytes")  # Add memory check
            retry_count = 0
            retry_delay = self.initial_retry_delay
            
            while retry_count < self.max_retries:
                # First try
                if retry_count == 0:
                    print("Calling wlan.connect()...")
                    self.wlan.connect(self.ssid, self.password)
                    print("After wlan.connect() call")
                    status = self.wlan.status()
                    print(f"WiFi status: {status}") 
                
                # Check connection status
                for i in range(10):  # Poll for up to 10*500ms = 5 seconds
                    print(f"Connection check {i+1}/10...")
                    if self.wlan.isconnected():
                        ip = self.wlan.ifconfig()[0]
                        print(f"Connected to WiFi. IP: {ip}")
                        self.wifi_connected = True
                        return True
                    time.sleep_ms(800)
                
                # If we got here, connection failed
                retry_count += 1
                print(f"Connection attempt {retry_count} failed")
                
                if retry_count >= self.max_retries:
                    print("Max retries reached. WiFi connection failed.")
                    break
                
                # Calculate next retry delay with exponential backoff
                retry_delay = min(retry_delay * self.backoff_factor, self.max_retry_delay)
                print(f"Retrying in {retry_delay}ms (attempt {retry_count+1}/{self.max_retries})")
                
                # Simple wait without LED blinking for testing
                time.sleep_ms(retry_delay)
            
            return False
        except Exception as e:
            print(f"Exception in connect_wifi: {e}")
            import sys
            sys.print_exception(e)  # Print full exception details
            return False   
    
    def start_server(self):
        """Start a simple HTTP server"""
        if not self.wifi_connected:
            print("Cannot start server: WiFi not connected")
            return False
        
        try:
            addr = socket.getaddrinfo('0.0.0.0', self.server_port)[0][-1]
            self.socket = socket.socket()
            self.socket.setsockopt(socket.SOL_SOCKET, socket.SO_REUSEADDR, 1)
            self.socket.bind(addr)
            self.socket.listen(1)
            
            print(f"Server started on port {self.server_port}")
            self.server_running = True
            return True
        except Exception as e:
            print(f"Failed to start server: {e}")
            return False
    
    def parse_request(self, request):
        """Parse an HTTP request and extract parameters"""
        try:
            # Extract the request line
            request_line = request.split('\r\n')[0]
            method, path, _ = request_line.split(' ')
            
            if method != 'GET':
                return {'error': 'Only GET requests are supported'}
            
            # Parse path and query parameters
            if '?' in path:
                path, query = path.split('?', 1)
                params = {}
                for param in query.split('&'):
                    if '=' in param:
                        key, value = param.split('=', 1)
                        params[key] = value
                return {'path': path, 'params': params}
            else:
                return {'path': path, 'params': {}}
        except Exception as e:
            print(f"Error parsing request: {e}")
            return {'error': 'Invalid request format'}
    
    def handle_request(self, client_sock, addr):
        """Handle an HTTP request from a client"""
        try:
            # Receive request
            request = client_sock.recv(1024).decode('utf-8')
            if not request:
                return
            
            # Parse the request
            parsed = self.parse_request(request)
            
            # Prepare response
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

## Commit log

2025-04-30 with circuit diagram
2025-09-01 Add comprehensive README files for all modules
    Introduced detailed README.md files for ABXTester, Firmware, PCB, Simulator, and the repository root. These documents provide overviews, setup instructions, technical summaries, and rationale for eac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
2025-09-01 Rename safety threshold to user specified threshold
    Updated all references from 'Safety Threshold' to 'User Specified Safety Threshold' for clarity in UI, documentation, and code comments. Added references and model description to README and results i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
